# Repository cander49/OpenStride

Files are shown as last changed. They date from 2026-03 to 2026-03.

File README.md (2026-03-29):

# OpenStride

OpenStride_white

**Note: For any questions related to installation or otherwise, please email collin.anderson@sydney.edu.au **  \
  \
  \
  \
  \
Welcome to **OpenStride**, an open-source platform that integrates both **hardware and software** for rodent behaviour recording and analysis using a force-plate actometer system. **Importantly, please read the following to ensure smooth installation of OpenStride.**. 

OpenStride is designed to provide a **low-cost, accessible, and reproducible** solution for laboratories studying locomotor and other behaviours. OpenStride was created by Collin Anderson's Laboratory in the School of Medical Sciences, The University of Sydney Faculty of Medicine and Health, with particular leadership by Biomedical Engineering MPhil student Yang Yang. For further technical detail please refer to the publication:

Yang et al. *OpenStride: an inexpensive, open-source force plate actometry system for quantification of rodent motor activity and behaviour.* Scientific Reports, 2026. https://www.nature.com/articles/s41598-026-44953-z
 
---

## Introduction

This repository contains the necessary files for the OpenStride system, consisting of two main folders:

- **Hardware** – contains the STL and SVG files, required for 3D printing and laser-cutting, as well as the Hardware Assembly Guide.
- **Software** – contains the downloadable program files for Windows and MacOS, as well as the Installation Guide for the respective operating systems.

Further information about each folder is below.

---

## Hardware



This folder contains the STL and SVG files for creating the platform that will **collect behavioural data**. Hardware Assembly Guide contains a walkthrough for the fabrication and assembly of the OpenStride system.

All assembly instructions, required files, and hardware documentation can be found here:

➡️ **[Hardware Assembly Guide](https://github.com/cander49/OpenStride/tree/main/hardware)**

This section includes:

- 3D printing files
- Laser cutting files
- Electronic components list
- Assembly instructions

The Hardware Assembly Guide includes:

- Overview
- Bill of Materials
- 3D Printing Guide
- Laser Cutting Guide
- OpenStride Assembly
- Troubleshooting 

---

## Software



This folder contains operating system dependent downloads, for MacOS and Windows. The programs within these folders require careful installation of various programs, ensure that you read through the Software Installation Guide. The OpenStride Software will be required for **recording data**, as well as the **processing of and analysing behavioural data**.

Separate versions are provided for different operating systems, with an installation guide on each page:

- **[Windows Version](https://github.com/cander49/OpenStride/tree/main/software/windows)**
- **[macOS Version](https://github.com/cander49/OpenStride/tree/main/software/mac/OpenStride%20-%20Mac)**

This section includes an installation list of external software, packages and toolboxes: 

- Python 3.10+
- Python Packages
- Phidget22
- MATLAB
- MATLAB Toolboxes

To ensure all dependencies are installed as the correct package version, run in the terminal in the same directory as OpenStride:

```bash
pip3 install -r requirements.txt
```

Further to this, if any dependency issues are occurring, consider using a virtual environment to isolate project dependencies, run in the terminal in the same directory as OpenStride:

```bash
python3 -m venv .venv # creating a virtual environment
# source .venv/bin/activate   # macOS
# .venv\Scripts\activate    # Windows
pip install -r requirements.txt
```

---

## Using OpenStride、

### Important Note (Dark Mode)
Before using the OpenStride UI, please ensure that **Dark Mode is turned off** on your operating system.

Due to limitations in **MATLAB App Designer**, the UI elements required for OpenStride may not display correctly when Dark Mode is enabled. This applies to both **Windows** and **macOS** systems.  
Please switch your system to **Light Mode** before launching the software.

---

### Default UI Interface

When OpenStride is launched, the UI opens in **Data Recording Mode** by default.

This mode requires that **both the hardware and software have been correctly installed and configured**.

Please ensure the following installation steps have been completed before attempting data acquisition:

*   [Link to Hardware Install](https://github.com/OpenStrideNeuro/OpenStride/tree/main/hardware)
*   [Link to Software Install](https://github.com/OpenStrideNeuro/OpenStride/tree/main/software)

Only after completing the above installation steps will the **data acquisition system function correctly**.

---

### Switching Between Recording and Analysis Modes

OpenStride UI Overview

The button highlighted in red in the image above is **“Switch to Analysis”**.

This button allows users to switch between:

- **Recording Mode (default)**
- **Analysis Mode**

You can switch between these modes at any time.
All settings and text entries made in either mode will **remain saved unless the UI is closed**.

---

### Calibration

Calibration lasts 30 seconds and is required under the following circumstances:

- When using OpenStride on **a newly installed computer**
- When the **OpenStride software has been freshly installed**
- When the **OpenStride hardware setup has been moved**
- When using **any new hardware**.
- When using **a different experimental setup**



If the plate and setup **have not been moved or modified**, calibration **does not need to be performed before every recording session**.

However, to ensure **maximum accuracy of trajectory data**, calibration is strongly recommended whenever any of the above changes occur. If commencing with calibration, ensure that no animal or object is placed on OpenStride for the duration of the calibration. Further, ensure that the surface that OpenStride is ontop of is not disturbed during calibration.

---

### Select Output Folder

Click **“Select Output Folder”** to choose the directory where the recorded data will be stored.



After selecting a folder:

- A dialog window will appear.
- Choose the directory where the data should be saved.
- The selected folder path will appear in the **white text box on the right side**.

This step is **mandatory** before starting data acquisition.

---

### Output File Name

The **Folder Output File Name** defines the name of the data file for the current recording session.

The system will automatically append the **`.csv` file extension**.

You may also use the dropdown arrow to select **previously used file names**.



⚠️ **Important**

Do **not reuse the same file name within the same output folder**.

If the same file name is used again in the same directory, the **new data file will overwrite the previous one**.

Please ensure that each recording session uses a **unique file name**.

---

### Notes Field

The **Note** field allows users to record experimental details.

These notes will be saved in the **header section of the CSV file**.



You may use this field to document:

- Experimental setup
- Animal information
- Environmental conditions
- Any other relevant notes

This field is optional and **can be left blank if not required**.

---

### Experimental Animal Selection

Users can select the experimental animal:

- **Mouse**
- **Rat**



In the current version of OpenStride, this option is used **only for experimental metadata storage**.

However, this setting will be used in future iterations as additional analyses are implemented, for example, grooming detection based on prior publication from Anderson et al: https://www.sciencedirect.com/science/article/pii/S0165027023002455

---

### Acquisition Settings

Within **Recording Mode**, the **Acquisition Settings** panel contains options for controlling recording behavior.

#### 1. Auto Stop

The **Auto Stop** option allows users to automatically stop recording after a specified duration.

Features include:

- User-defined recording duration
- Time unit selection (**minutes or hours**)
- Real-time display of:
  - Remaining time
  - Total recorded time



---

#### 2. Discard First (Delay Start)

If researchers prefer to **leave the room after placing the animal in the enclosure**, this feature allows a delay before recording begins.

This ensures that **experimenter presence does not affect the animal's natural behavior**.



Settings include:

- Delay duration configurable in **seconds or minutes**
- The initial delay period will **not be included in the final data**

For example:

If a **2-second delay** is set, valid recording data will begin **2 seconds after pressing “Start Recording”**.

---

#### 3. Sample Frequency

The **Sample Frequency** determines the sensor sampling rate.

Since OpenStride uses a **Fidelity DAC card**, it supports a **range of sampling frequencies**.

Users can select the desired frequency from the **dropdown menu** within the supported range.



---

### Start Recording

After configuring all settings place the animal onto the force-plate and click **“Start Recording”**.



Once recording begins:

- The system starts collecting sensor data
- A new window will appear displaying an **animated trajectory chart**
- The chart updates **in real time** as the animal moves

---
### Analysis Mode

To enter the **Analysis Mode**, click the **“Switch to Analysis”** button located at the top of the UI.

Once inside the Analysis Mode, you can click **“Switch to Record”** at any time to return to **Recording Mode**.



---

### Import Data

Click **“Import Data”** to open a file selection window.

From this window, you can select the data files you wish to analyse.  
Multiple files can be selected at the same time.

After importing the data, the files will appear in the **File List**.



---

### Organising the Analysis Order

The order of the files in the list determines the **analysis sequence**.

This becomes important when analysing data from the **same animal across multiple sessions**.

In future analysis steps, when clicking **“Start Analysis”**, users may choose to **combine all selected data files into a single analysis**.  
In such cases, organising the correct order ensures the combined dataset follows the intended sequence.

The **Remove** function allows users to remove any unwanted data files from the list.

This is useful if:

- A file was imported accidentally
- The wrong dataset was selected
- Certain files should not be included in the current analysis

Removing unnecessary files helps keep the analysis workflow clean and organised.

---

### Analysis Methods

Currently, the software includes four analysis methods:

1. **Distance / Speed**
2. **Low Mobility Bouts**
3. **Tremor**
4. **Ataxia**

Future versions may include additional analysis modules.

Since **OpenStride is an open-source project**,  developers can add their **own analysis methods**.

New analysis modules can be implemented through **MATLAB App modules**, allowing users to extend the software with custom analysis pipelines.

---

### Output Folder Path

Before running the analysis, users must specify the **Output Folder Path**.



All generated outputs will be saved in this location, including:

- Result figures
- Numerical results
- Exported text files
- Analysis summaries

---

### Folder Name

Users can optionally define a **Folder Name** for the analysis results.

If no name is specified, the system will automatically generate a **unique folder name based on the timestamp when “Start Analysis” is clicked**.



---

### Analysis Results

Below are examples of the generated analysis outputs.

The results include visualisations and numerical summaries for:

1. **Distance / Speed**
2. **Low Mobility Bouts**
3. **Tremor**
4. **Ataxia**

All generated figures, tables, and result files will be automatically saved in the **selected output directory**.

---

### Additional Notes

Please note that load cells in this design are rated for 300 grams per cell. With an overload of more than 300 grams on a single cell, a temporary, small degreee of accuracy loss will occur, and if more than 750 grams is applied to a single cell, it is likely irreperable damage will likely occur, in which case that load cell will need to be replaced. We recommend that rats used are not greater than 500 grams, and in the future, we will update with additional optimisation approaches in a species-specific manner.

---



****

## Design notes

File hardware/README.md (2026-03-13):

# OpenStride – Hardware Assembly Guide

---

This guide walks you through fabricating and assembling the OpenStride hardware, including 3D printing, laser cutting, and mechanical assembly.

> **Note:** Complete all fabrication steps (Parts 1 and 2) before beginning assembly (Part 3).

---

## Overview

| # | Step | What you are doing |
|---|---|---|
| 1 | **3D Printing** | Print the structural components in PLA |
| 2 | **Laser Cutting** | Cut the acrylic enclosure panels |
| 3 | **Assembly** | Connect sensors, route wiring, and close the enclosure |

---

## Bill of Materials

| Category | Component | Specification | Source |
|---|---|---|---|
| **3D-printed parts** | Walk plate (×1) | PLA, 40–60% infill | [STL files](https://github.com/cander49/OpenStride/blob/main/hardware/3d%20files/walk%20plate.stl) |
| | Plate holders (×4) | PLA, 40–60% infill | [STL files](https://github.com/cander49/OpenStride/blob/main/hardware/3d%20files/plate%20holder.stl) |
| | Base plate (×1) | PLA, 40–60% infill | [STL files](https://github.com/cander49/OpenStride/blob/main/hardware/3d%20files/baseplate.zip) |
| | Electronics chamber lid (×1) | PLA, 40–60% infill | [STL files](https://github.com/cander49/OpenStride/blob/main/hardware/3d%20files/lid.stl)|
| **Laser-cut parts** | Acrylic enclosure Part A (×4) | 5 mm clear acrylic, 35 × 45 cm | [SVG file](https://github.com/cander49/OpenStride/blob/main/hardware/laser%20cut%20files/Acrylic%20enclosure%20Part%20A.svg) |
| | Acrylic enclosure Part B (×4) | 5 mm clear acrylic, 35 × 45 cm | [SVG file](https://github.com/cander49/OpenStride/blob/main/hardware/laser%20cut%20files/Acrylic%20enclosure%20fillet%20Part%20B.svg) |
| **Ballast** | Concrete ballast | 35 × 35 × 5 cm | — |
| **Fasteners** | M3.5 flat-head screws (×8) | 316/316L stainless steel, 8 mm | — |
| | M3.5 flat-head screws (×8) | 316/316L stainless steel, 25 mm | — |
| **Sensors** | Single-point load cells (×4) | Tedea Huntleigh Model 1004, 300 g capacity | Tedea-Huntleigh |
| **Padding** | High-density EVA foam (×4) | ~100 kg/m³, ~50 Shore A, 3 × 3 × 2 cm | — |
| **Adhesive** | Cyanoacrylate super glue | e.g. 502 or equivalent | — |
| **DAQ** | PhidgetBridge DAQ card | PhidgetBridge 1046_0B | Phidgets Inc. |
| **Connectivity** | USB cable | USB-A / USB-C | — |

---

# Part 1 – 3D Printing

---

## What needs to be printed

| Component | Quantity |
|---|---|
| Base plate | ×1 |
| Electronics chamber lid | ×1 |
| Workplate holder | ×4 |
| Workplate | ×1 |

STL files for all components are available in the Supplementary materials.

---

## Printer requirements

OpenStride's components require a printer with a **minimum build platform of 35 × 35 cm**.

> 💡 **Don't have access to a suitable printer?** Contact your institution's faculty or makerspace, or search for a local print service that supports this bed size.

---

## Print settings

| Parameter | Recommendation |
|---|---|
| **Material** | PLA |
| **Layer height** | No strict requirement — adjust to your desired surface quality. Layer height has no known effect on experimental results. |
| **Infill density** | 40–60% for most components (see note on Workplate below) |
| **Slicer software** | Any slicer works. [Creality Print 6.2](https://www.creality.com/pages/download-software) was used in the paper, but the design is not printer-specific. |

---

## Step 1.1 – Slice the STL Files

1. Open your slicer software
2. Import the STL files from the Supplementary materials
3. Apply the print settings from the table above
4. Slice and export the file to your printer

---

## Step 1.2 – Print All Components

Print each component listed in the table above. Recommended print order:

1. Base plate
2. Electronics chamber lid
3. Workplate holders (×4)
4. Workplate

---

## Note on Workplate Weight

The Workplate's infill density and height can be adjusted in the STL file to achieve different weights. The effect of plate weight on data collection is discussed in the paper's Supplementary section.

> ⚠️ **Note:** The Supplementary data on workplate weight may not yet be available. If you need this information, check back later or contact the OpenStride team.

---

# Part 2 – Laser Cutting

---

## What needs to be cut

| Component | Quantity | Material | Dimensions |
|---|---|---|---|
| Acrylic enclosure Part A | ×4 | 5 mm acrylic sheet | 35 × 45 cm |
| Acrylic enclosure Part B | ×4 | 5 mm acrylic sheet | 35 × 45 cm |

The SVG cut file for both parts is available in the Supplementary materials.

---

## Material selection

The enclosure material and colour can be chosen based on your experimental setup. The paper uses **5 mm clear acrylic**, which allows for visual inspection of the internal electronics.

> 💡 **Alternative options:** Coloured or opaque acrylic can be used if light isolation is required for your experiment.

---

## Step 2.1 – Prepare the Cut File

1. Download the SVG file from the Supplementary materials
2. Open it in your laser cutter's software
3. Confirm the cut dimensions match your acrylic sheet size

---

## Step 2.2 – Cut the Enclosure Panels

1. Place your acrylic sheet in the laser cutter
2. Run the cut job for Part A — cut **4 pieces**
3. Run the cut job for Part B — cut **4 pieces**
4. Remove the finished panels and peel off any protective film

> ⚠️ **Safety:** Always follow your laser cutter's safety guidelines. Do not leave the machine unattended during cutting.

---

## Step 2.3 – Glue the Enclosure Together

Use **cyanoacrylate super glue** (e.g. 502 or equivalent) to bond the acrylic panels together:

1. Dry-fit all 8 panels before applying glue to confirm alignment
2. Apply a thin, even layer of glue to each joining edge
3. Press the panels firmly together and hold for 30–60 seconds per joint
4. Allow the fully assembled enclosure to cure before handling

> ⚠️ **Safety:** Work in a well-ventilated area. Cyanoacrylate fumes are irritating — avoid prolonged inhalation and keep away from eyes.

> 💡 **Tip:** Assemble on a flat surface to ensure the base of the enclosure sits level.

---

# Part 3 – Assembly

Before starting, make sure you have all 3D-printed parts, the assembled acrylic enclosure, sensors, screws, foam pads, and the DAQ card ready.

---

## Step 3.1 – Attach Load Cells to Base Plate

Attach each of the **4 load cells** to the **base plate** using the **8 mm M3.5 screws** (2 screws per sensor).

---

## Step 3.2 – Attach Workplate Holders to Load Cells

Attach each of the **4 workplate holders** to its corresponding **load cell** using the **25 mm M3.5 screws** (2 screws per holder).

---

## Step 3.3 – Route and Connect Sensor Cables

> ⚠️ **Important:** Follow this step carefully. Incorrect wiring may damage the sensors or DAQ card.

### 3.3a – Route cables through the Electronics Chamber

The Electronics Chamber has **four holes**, one at each corner, corresponding to the four sensors.

1. Identify the four cable routing holes on the Electronics Chamber
2. Feed each sensor's tri-colour cable through the hole **nearest to it** — do not cross cables between corners
3. Ensure cables are not pinched or kinked

### 3.3b – Connect cables to the PhidgetBridge 4-Input

Each sensor has a **4-wire cable**. Connect each wire to its correct terminal on the **PhidgetBridge 1046_0B**, following the colour mapping below:

| Wire colour | Signal | Terminal label |
|---|---|---|
| 🔴 Red | Positive (+) | + |
| ⬛ Black | Ground (G) | G |
| ⬜ White | Negative (−) | − |
| 🟢 Green | 5V Power | 5V |

Connect each sensor to its corresponding **Port** on the PhidgetBridge, in the order below. The port number must match the physical corner of the device:

| Port | Corner position | Location |
|---|---|---|
| Port 0 | Corner 0 | Bottom Right |
| Port 1 | Corner 1 | Upper Right |
| Port 2 | Corner 2 | Upper Left |
| Port 3 | Corner 3 | Bottom Left |

> ⚠️ **Do not swap ports between corners.** Misconnection will cause incorrect data mapping and may damage the load cells.

Refer to the diagram below for the exact corner layout and port assignment:

![Cable connection diagram — PhidgetBridge port-to-corner mapping](1a5f50f95c85a5741c840d64c8c64087

---

## Step 3.4 – Close the Electronics Chamber

1. Place the **electronics chamber lid** over the chamber
2. Secure it in place
3. Set the **workplate** on top of the workplate holders

---

## ✅ Assembly Complete

Your OpenStride hardware is now fully assembled. You should have:

- ✅ 4 load cells mounted to the base plate
- ✅ 4 workplate holders attached to the load cells
- ✅ All sensor cables routed through the electronics chamber
- ✅ All cables connected to the correct ports on the PhidgetBridge DAQ card
- ✅ Electronics chamber lid closed
- ✅ Workplate placed on top

You are now ready to connect the hardware to your computer and proceed with software setup. See the **[Windows Installation Guide](https://github.com/cander49/OpenStride/tree/main/software/windows)** or **[macOS Installation Guide](https://github.com/cander49/OpenStride/tree/main/software/mac/OpenStride%20-%20Mac)** for next steps.

---

## Troubleshooting

| Problem | Solution |
|---|---|
| Screw holes don't align | Check that the correct screw length is being used (8 mm for base plate, 25 mm for workplate holders) |
| Sensor cable won't reach the DAQ card | Re-route cables before closing the electronics chamber lid |
| Workplate is unstable | Check that all 4 workplate holders are fully tightened |
| Acrylic panels don't fit together | Dry-fit all panels before gluing — verify cut dimensions match the SVG file |
| Acrylic joint is weak or failed | Reapply cyanoacrylate glue and allow full cure time before handling |
| DAQ card not detected by computer | Check the USB connection and confirm Phidget22 drivers are installed |

> 💬 If you continue to experience issues, please get in contact with the OpenStride team.
 
---

*OpenStride Hardware Assembly Guide · Last updated 2026*

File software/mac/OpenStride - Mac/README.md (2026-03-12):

# OpenStride – macOS Installation Guide

---

This guide walks you through setting up all required software on **macOS** so that OpenStride can collect and process data from its physical devices.

> **Note:** Please install each component in the order listed below. Skipping ahead may cause errors.

---

## Installation: what you need to install

| # | Component | Purpose |
|---|---|---|
| 1 | **Python 3.10+** | Collects data from OpenStride hardware |
| 2 | **Python packages** | Libraries that OpenStride depends on |
| 3 | **Phidget22 drivers** | Enables communication with Phidget hardware devices |
| 4 | **MATLAB** | Processes and analyses the collected data |
| 5 | **MATLAB toolboxes** | Required MATLAB add-ons for OpenStride's analysis pipeline |

---

## Quick Start

**Requirements:** macOS 12 (Monterey) or later · Python 3.10+ · A valid MATLAB license

**[1]** Install Python (3.10 or later) from the official website:

🔗 [https://www.python.org/downloads/](https://www.python.org/downloads/)

**[2]** Install OpenStride's required Python packages. Navigate to your OpenStride project folder in Terminal and run:

```bash
pip3 install -r requirements.txt
```

**[3]** Install the Phidget22 drivers for macOS:

🔗 [Phidget22 macOS Installer](LINK)

**[4]** Install MATLAB R2025a and the required toolboxes:

🔗 [https://www.mathworks.com/downloads/](https://www.mathworks.com/downloads/)

---

## Detailed Installation

The sections below walk through each step in detail.

---

# Part 1 – Python

Python is a free, open-source programming language. OpenStride uses Python to collect data from its hardware — handling the communication between your computer and the physical devices connected to it.

> **Currently, only Python 3.10+ is supported.**

---

### Step 1.1 – Download Python

Go to the official Python downloads page and download the macOS installer:

🔗 [https://www.python.org/downloads/](https://www.python.org/downloads/)

The page should automatically suggest the latest version for macOS. Click **Download Python 3.x.x** to begin.

---

### Step 1.2 – Run the Installer

1. Open your **Downloads** folder
2. Double-click the file (e.g. `python-3.x.x-macos11.pkg`)
3. Follow the on-screen steps and click **Continue** through each screen
4. Click **Install** when prompted — macOS may ask for your password
5. Click **Close** when the installation is complete

---

### Step 1.3 – Verify

Open **Terminal** (`Cmd + Space` → search `Terminal` → press Enter) and run:

```bash
python3 --version
```

Expected output:

```
Python 3.x.x
```

✅ You see a version number → move to Part 2.  
❌ You see `command not found` → the installer may not have completed correctly. Repeat Step 1.2.

> 💡 **Note:** On macOS, always use `python3` instead of `python`, and `pip3` instead of `pip`.

---

# Part 2 – Python Packages

Python packages are libraries that extend Python's functionality. OpenStride lists all its required packages in a file called `requirements.txt`, included in the project folder.

---

### Step 2.1 – Navigate to the OpenStride Folder

Open **Terminal** and navigate to where you downloaded OpenStride. Replace the path below with your actual folder location:

```bash
cd /Users/YourName/Downloads/OpenStride
```

> 💡 **Tip:** In Finder, open the OpenStride folder, then drag the folder icon from the top of the Finder window directly into Terminal — it will paste the full path automatically.

---

### Step 2.2 – Install Packages

Run the following command:

```bash
pip3 install -r requirements.txt
```

This automatically installs everything OpenStride needs. It may take a few minutes.

Wait until you see:

```
Successfully installed [packages...]
```

✅ Installation successful → move to Part 3.  
❌ You see an error → confirm you are in the correct folder and that Python installed correctly (Part 1).

---

# Part 3 – Phidget22 Drivers

Phidget22 drivers enable OpenStride to communicate with the Phidget sensor hardware connected to your computer. Without these drivers, OpenStride cannot read from the physical devices.

---

### Step 3.1 – Download and Install

Download Phidget22 from the link below:

🔗 [Phidget22 macOS Installer](LINK)

1. Open the downloaded `.dmg` file
2. Follow the on-screen instructions to complete the installation
3. If macOS shows a security warning, go to **System Settings** → **Privacy & Security** → click **Allow Anyway**

---

### Step 3.2 – Verify

Open **Phidget Control Panel** from your Applications folder. If it opens without errors, the drivers are installed correctly.

> 💡 **Tip:** Once calibrated, you can close and reopen the app without needing to recalibrate.

---

# Part 4 – MATLAB

MATLAB is a numerical computing environment. OpenStride uses MATLAB to process and analyse the motion data collected from the hardware.

> ⚠️ **MATLAB requires a paid license and OpenStride requires MATLAB R2025a.** If you do not already have one, contact your institution or lab administrator.

---

### Step 4.1 – Download and Install

Sign in to your MathWorks account and download the MATLAB installer for macOS:

🔗 [https://www.mathworks.com/downloads/](https://www.mathworks.com/downloads/)

1. Open the downloaded `.dmg` file
2. Double-click the MATLAB installer
3. Sign in with your MathWorks account when prompted
4. Follow the on-screen steps to complete the installation

---

### Step 4.2 – Verify

Open MATLAB from your **Applications** folder. Confirm it launches without errors.

---

# Part 5 – MATLAB Toolboxes

MATLAB toolboxes are official add-ons that extend what MATLAB can do. OpenStride's analysis pipeline depends on several specific toolboxes.

---

### Step 5.1 – Open the Add-On Manager

In MATLAB, go to **Home** → **Add-Ons** → **Get Add-Ons**.

---

### Step 5.2 – Install Required Toolboxes

Search for and install each of the following toolboxes:

| Toolbox | Version |
|---|---|
| **Image Processing Toolbox** | R2025a |
| **Signal Processing Toolbox** | R2025a |
| **Simulink 3D Animation** | R2025a |
| **Statistics and Machine Learning Toolbox** | R2025a |

For each toolbox: search by name → click the result → click **Install**.

---

### Step 5.3 – Verify

In the MATLAB Command Window, run:

```matlab
ver
```

Check that all required toolboxes appear in the output list.

---

# ✅ Installation Complete

You have successfully installed all components required to run OpenStride:

- ✅ Python 3.10+
- ✅ Python packages
- ✅ Phidget22 drivers
- ✅ MATLAB R2025a
- ✅ MATLAB toolboxes

You are now ready to launch OpenStride. See the **[Quick Start Guide](#)** for your first steps with the software.

---

## Troubleshooting

| Problem | Solution |
|---|---|
| `command not found: python3` | Reinstall Python from [python.org](https://www.python.org/downloads/) |
| `command not found: pip3` | Same as above — Python did not install correctly |
| macOS blocks the Phidget22 installer | Go to **System Settings** → **Privacy & Security** → click **Allow Anyway** |
| Phidget Control Panel won't open | Restart your computer after the Phidget22 installation |
| MATLAB licence error | Verify your MathWorks licence is active at [mathworks.com](https://www.mathworks.com) |
| A required MATLAB toolbox is missing | Re-open Add-On Manager and search for the toolbox again |

> 💬 If you continue to experience issues, please get in contact with the OpenStride team.
---

*OpenStride macOS Installation Guide · Last updated 2026*

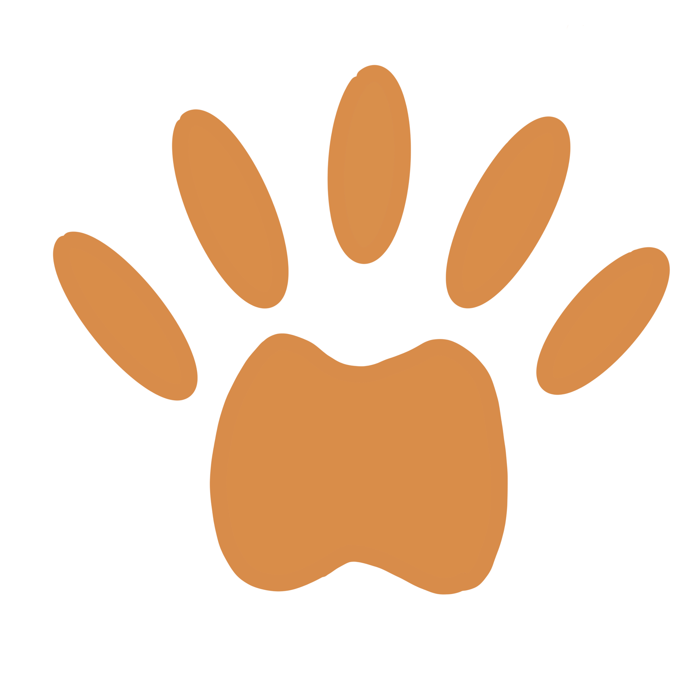
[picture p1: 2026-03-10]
software/mac/OpenStride - Mac/phidget/f.png

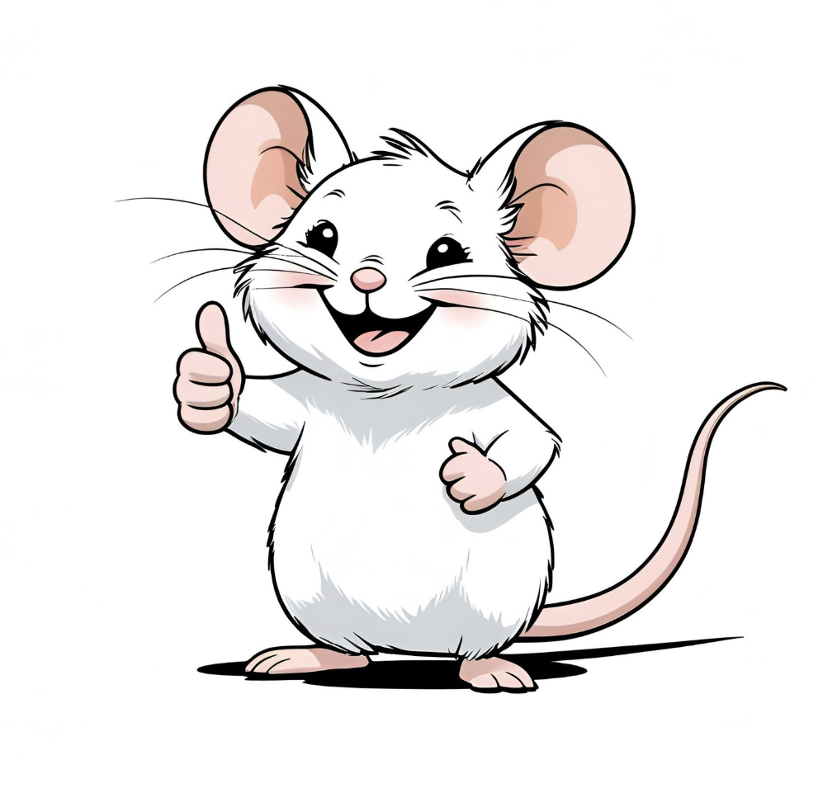
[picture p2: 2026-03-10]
software/mac/OpenStride - Mac/complete.png

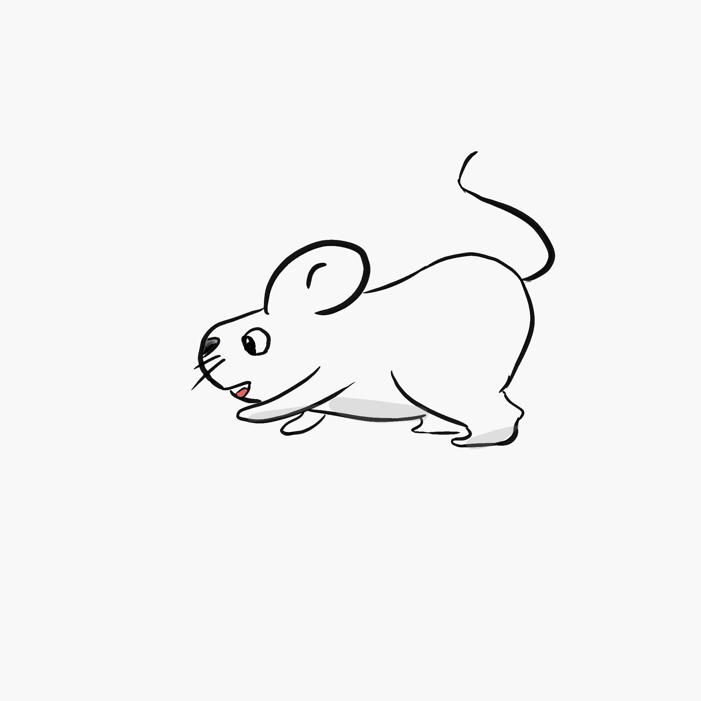
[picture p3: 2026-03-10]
software/mac/OpenStride - Mac/progress.gif

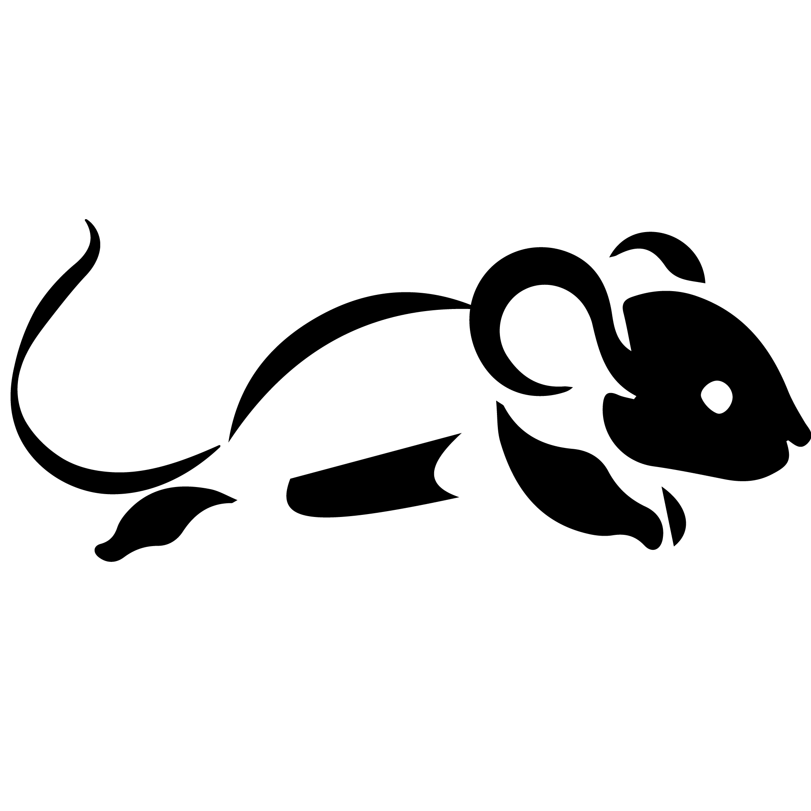
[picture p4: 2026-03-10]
software/mac/OpenStride - Mac/OpenStride_square.png

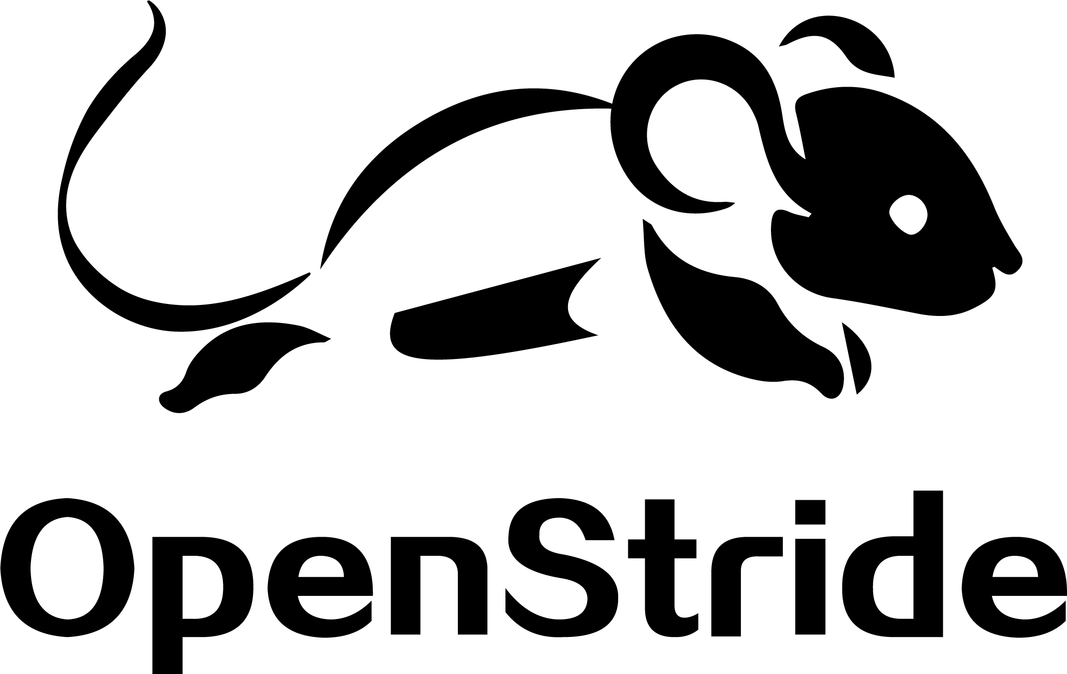
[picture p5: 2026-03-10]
software/mac/OpenStride - Mac/OpenStride.png

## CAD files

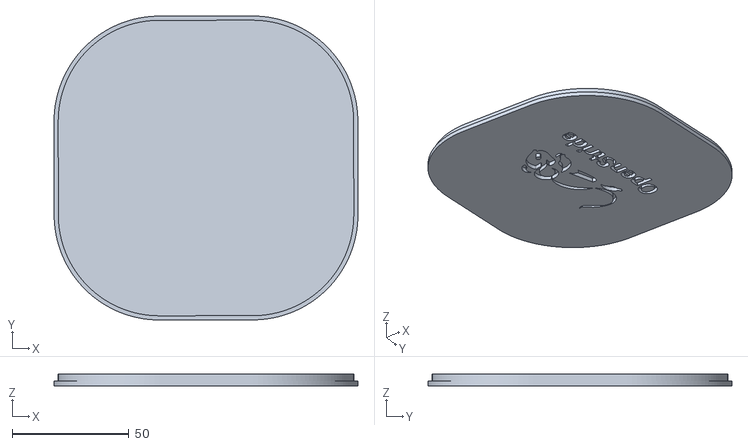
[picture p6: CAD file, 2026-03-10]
hardware/3d files/lid.stl
130.0 x 130.0 x 5.00

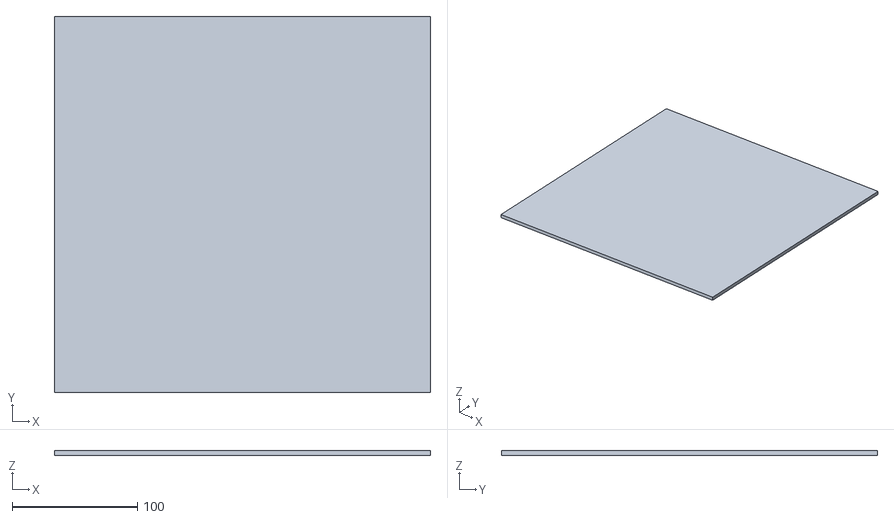
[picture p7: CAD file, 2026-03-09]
hardware/3d files/walk plate.stl
300.0 x 300.0 x 4.00

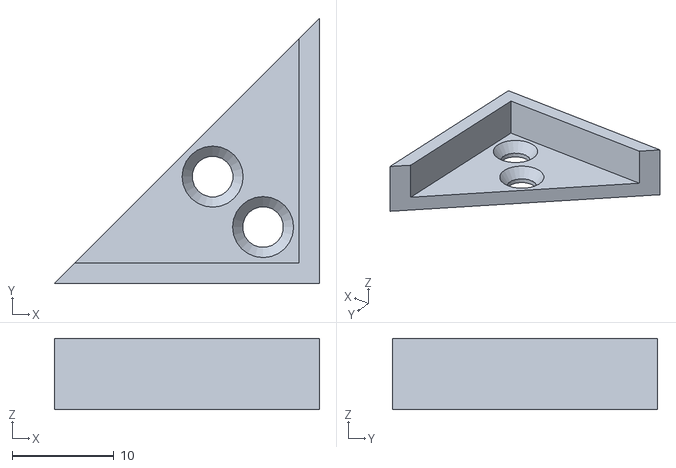
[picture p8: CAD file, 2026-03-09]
hardware/3d files/plate holder.stl
26.0 x 26.0 x 7.00

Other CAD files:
hardware/3d files/baseplate.stl
